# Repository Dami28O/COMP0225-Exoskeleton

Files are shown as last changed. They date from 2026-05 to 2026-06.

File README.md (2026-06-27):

# TSA Wearable Exosuit — Sit-to-Stand Assistance

<p align="center">
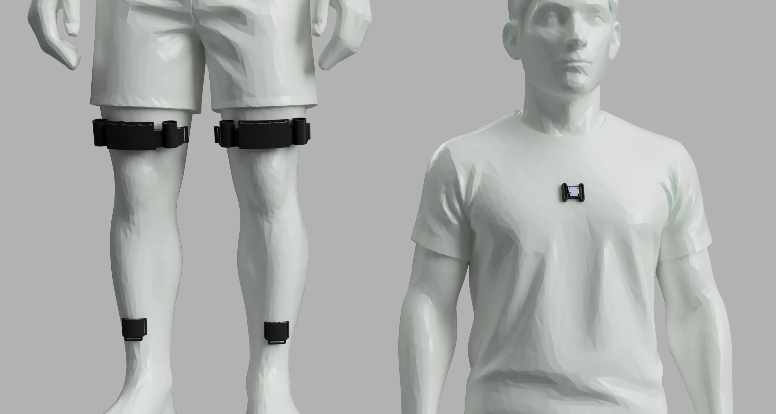
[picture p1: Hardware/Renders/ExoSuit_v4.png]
ExoSuit v4 render
  
</p>

A Twisted String Actuator (TSA) based wearable exosuit designed to assist users through sit-to-stand (STS) motions. Motor performance is optimised using Proximal Policy Optimisation (PPO). An IMU-based intention detection system determines when to trigger the device, and a MuJoCo/MyoSuite musculoskeletal simulation validates the assist strategy before physical deployment.

---

## Results

- **Muscle activation reduction:** 10% reduction in lower-limb muscle activation on a single test subject
- **Intention detection accuracy:** 84.38% overall — limited by false positives from similar forward-lean motions (e.g. bending to tie shoelaces)
- **Control optimisation:** PPO-optimised TSA parameters (string length, staggered motor activation times) minimise quadriceps demand while tracking baseline kinematics

---

## System Overview

```
┌─────────────────────────────────────────────────────┐
│                   Wearable Exosuit                  │
│                                                     │
│  ┌──────────────────┐     ┌──────────────────────┐  │
│  │ Intention        │────▶│ Hardware Control     │  │
│  │ Detection (IMU)  │     │ (TSA Motors + EMG)   │  │
│  └──────────────────┘     └──────────────────────┘  │
│                                    ▲                │
│  ┌──────────────────┐              │                │
│  │ Simulation &     │──── PPO ─────┘                │
│  │ Optimisation     │  optimised params             │
│  └──────────────────┘                               │
└─────────────────────────────────────────────────────┘
```

The three subsystems map directly to the three directories in this repository.

---

## Repository Structure

```
COMP0225-Group3/
│
├── Hardware/
│   ├── MotoronWifiControl.ino   # Arduino firmware — motor control + EMG logging
│   └── Renders/
│       └── ExoSuit_v4.png       # CAD render of the physical device
│
├── IntentionDetection/
│   ├── intent-detect.py         # Finite state machine — real-time STS intent detection
│   ├── complimentary-filter.py  # Complementary filter orientation estimate
│   ├── madgwick-filter.py       # Madgwick filter implementation
│   ├── visualise.py             # Sensor data visualisation
│   ├── read-all.py              # Raw IMU data logger
│   └── icm20948-python-main/    # ICM-20948 IMU driver (third-party)
│
└── Simulation/                  # See Simulation/README.md for full detail
    ├── train_ppo.py             # PPO training — torque-tracking reward
    ├── train_ppo_min_control.py # PPO training — min-control / baseline-tracking
    ├── train_ppo_feedback.py    # PPO training — multi-step feedback controller
    ├── run_optimal.py           # Replay best PPO policy
    ├── ctrl_optim/              # PPO wrappers, STS reflex controller, TSA integration
    ├── tsa_modelling/           # TSA physics (string geometry + motor ODE)
    └── myoassist/               # MyoSuite fork with TorsoLegs environment
```

---

## Hardware

The physical exosuit uses four Motoron motor controllers (I²C addresses 1–4), each driving two motors, giving eight TSA motors in total (four per leg). The microcontroller is an Arduino GIGA R1, which runs the firmware at `Hardware/MotoronWifiControl.ino`.

**Key firmware features:**

- Wi-Fi web interface for manual speed control and braking during development
- Continuous EMG logging via a MyoWare sensor on analogue pin A0 (12-bit, 50 ms interval)
- Acceleration and deceleration limits (400 counts/s²) on all motors to prevent jerk
- Three control modes: `DRIVE`, `BRAKE` (active braking at 800 counts), and `COAST`
- Command timeout (2 s) — motors safe-stop automatically if communication is lost

The TSA motors are twisted-string actuators: a brushed DC motor winds a pair of strings, converting rotation into linear contraction. This contraction applies an extension torque at the knee joint without any rigid linkage on the exosuit frame.

---

## Intention Detection

**Directory:** `IntentionDetection/`

The intention detection system uses an ICM-20948 9-DOF IMU mounted on the torso. Orientation is estimated in real time using a Madgwick filter (quaternion-based, fused accelerometer + gyroscope + magnetometer). The filtered pitch angle and its rate of change feed a finite state machine that fires a motor trigger when a sit-to-stand intent is confirmed.

**Detection rules (all must hold simultaneously):**

| Rule | Condition | Value |
|---|---|---|
| Forward lean | Pitch > threshold | 15° |
| Active lean | Pitch velocity > threshold | 20°/s |
| Positive acceleration | Smoothed pitch accel > 0 | 10-sample window |
| Sustained | Held for duration | 300 ms |
| Cooldown | Minimum gap between triggers | 5 s |

**Performance:** 84.38% overall accuracy. The primary source of false positives is other forward-lean motions — bending over to tie shoelaces, pick something up from the floor, etc. — which produce a similar pitch signature.

Additional scripts:

- `complimentary-filter.py` — earlier complementary filter orientation estimate
- `visualise.py` — real-time and post-hoc sensor data plots
- `read-all.py` — raw IMU data logger for offline analysis

---

## Simulation & Optimisation

**Directory:** `Simulation/` — see [`Simulation/README.md`](Simulation/README.md) for full documentation.

A MuJoCo/MyoSuite simulation drives the optimisation. The musculoskeletal model (`TorsoLegs`) has ~80 Hill-type muscles. A 4-phase reflex-based biological controller executes the STS motion; the TSA exosuit layer injects additional knee-extension torque on top.

**TSA physics** are modelled explicitly:

- String contraction: `X(θ) = L − sqrt(L² − (θ·r)²)`
- Motor dynamics: RK4 ODE integrator, handles stall and wall conditions
- 4-motor-per-leg layout with staggered activation times and symmetric frontal moment cancellation

**Three PPO pipelines** are implemented, all using Stable Baselines 3:

| Pipeline | Optimises | Reward focus |
|---|---|---|
| Torque-tracking | String length + 4 activation times | Minimise torque under-delivery |
| Min-control | String length + 4 activation times | Reduce VAS activation, track baseline kinematics |
| Feedback | Per-step torque commands | Real-time adaptive assist (22-feature observation) |

The min-control pipeline was used to derive the parameters deployed on the physical device.

### Quick Start

```bash
# Activate simulation environment
source Simulation/myoassist/.myo-venv/bin/activate

# Run one STS episode manually
mjpython Simulation/base_code.py

# Train with min-control PPO
mjpython Simulation/train_ppo_min_control.py --timesteps 5000 --out Simulation/logs/test_run

# Evaluate best parameters
mjpython Simulation/ctrl_optim/eval_best_min_control.py --run Simulation/logs/test_run
```

All simulation scripts require `mjpython` (MuJoCo's bundled Python runtime). See `Simulation/README.md` for the full command reference, configuration options, evaluation scripts, and plotting tools.

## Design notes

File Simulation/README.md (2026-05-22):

# TSA Exoskeleton — Sit-to-Stand Simulation

MuJoCo/MyoSuite simulation of a Twisted String Actuator (TSA) knee exoskeleton assisting a musculoskeletal model through sit-to-stand (STS). Includes a reflex-based biological controller, TSA physics, and three PPO training pipelines.

---

## Project Structure

```
TSAExoskeletonSTS/
│
├── base_code.py                    # Run one STS episode manually (useful for debugging)
├── train_ppo.py                    # PPO training — torque-tracking reward
├── train_ppo_min_control.py        # PPO training — min-control / baseline-tracking reward
├── train_ppo_feedback.py           # PPO training — multi-step feedback controller
├── train_ppo_feedback_resume.py    # Resume a feedback PPO run from a checkpoint
├── run_optimal.py                  # Replay best PPO policy deterministically
├── plot_tsa_log.py                 # Plot TSA actuator state logs (CSV → PNG)
├── plot_diag_p4.py                 # Plot Phase 3→4 stability diagnostics
│
├── ctrl_optim/
│   ├── sts_ctrl.py                 # 4-phase STS reflex controller (core sim loop)
│   ├── sts_ctrl_ari.py             # Reference controller variant (read-only)
│   ├── tsa_integration_full.py     # 4-motor-per-leg TSA physics wrapper
│   ├── tsa_integration.py          # Single-motor-per-leg wrapper (earlier version)
│   ├── ppo_wrapper.py              # Gymnasium env — torque-tracking PPO
│   ├── ppo_wrapper_min_control.py  # Gymnasium env — min-control PPO
│   ├── ppo_feedback_wrapper.py     # Gymnasium env — multi-step feedback PPO
│   ├── ppo_config.py               # Shared config dataclass for all PPO runs
│   ├── grid_search.py              # Grid search over TSA params (pre-PPO baseline)
│   ├── eval_best_min_control.py    # Replay best sampled θ from a min-control run
│   ├── extract_muscle_log.py       # Compare baseline vs TSA muscle activation
│   └── ppo_evaluation/
│       ├── compare_baseline_assisted.py  # Side-by-side plots + effort summary
│       ├── plot_ppo_eval.py              # Per-episode reward curve plots
│       └── plot_reward_curve.py          # Reward curve from training CSV
│
├── tsa_modelling/
│   ├── model_v2.py                 # TSASimulator — string geometry + speed-torque curve
│   └── actuator.py                 # TSAActuator — RK4 motor ODE integrator
│
├── myoassist/                      # MyoSuite fork with TorsoLegs environment
├── observations/                   # Notes on observations, stability, TSA signals
├── support_docs/                   # Handoff notes, model notes, design docs
└── logs/                           # Training outputs (git-ignored)
```

---

## Simulation Environment

The model is `TorsoLegs`, registered by MyoSuite. It's a lower-body musculoskeletal model with ~80 Hill-type muscles, driven by activation signals in [0, 1]. The root is defined by three joints: `root_x` (slide), `root_z` (slide), `root_pitch` (hinge) — not a free-joint quaternion.

```bash
from myosuite.utils import gym
env = gym.make("TorsoLegs")
```

All scripts require `mjpython` (MuJoCo's bundled Python runtime) rather than the system Python:

```bash
source myoassist/.myo-venv/bin/activate
which mjpython
```

---

## TSA Physics Model

### String geometry (`tsa_modelling/model_v2.py`)

Contraction as a function of motor angle θ:

```
X(θ) = L − sqrt(L² − (θ·r)²)
```

`L` is the untwisted string length (the key PPO-optimised parameter). `J = dX/dθ` maps motor speed to cable speed.

### Motor ODE (`tsa_modelling/actuator.py`)

`TSAActuator.step()` runs RK4 at each sim timestep. Three branches:

| Branch | Condition | Behaviour |
|---|---|---|
| `at_wall` | X ≥ X_max | String fully wound; motor stalls |
| `load_stalled` | τ_desired > τ_available | Motor stalls against load |
| `advancing` | Otherwise | Full EOM integration: I·θ̈ = τ_cmd − τ_load |

Returns `tension`, `torque`, `X`, `theta`, `theta_dot`, `at_wall`, `load_stalled`.

Key motor parameters (set in `tsa_integration_full.py → _build_tsa_sim`):

| Parameter | Value |
|---|---|
| `radius` | 4 mm |
| `max_motor_torque` | 0.1668 N·m (1.7 kg·cm) |
| `no_load_speed` | 800 RPM |
| `pretension_theta` | 20π rad (10 turns) |
| `max_contraction_ratio` | 0.30 |

---

## TSA Integration (`ctrl_optim/tsa_integration_full.py`)

**4-motor layout per leg.** Two central motors (offset 0°), one at +8°, one at −8°. Sagittal torque per motor: `τ_i = T_i × d × cos(α_i)`. Symmetric ±α pairs cancel frontal moments.

**Staggered activation.** Each motor has an `activation_time` [s]; it's inactive until `t >= activation_time`. PPO optimises these times.

**Cable slack model.** A motor delivers zero torque until its contraction `X` exceeds the geometric slack threshold:
```
X_geom = X₀ + MOMENT_ARM × max(0, knee_initial − knee_current)
```

**Torque injection into MuJoCo:**
```python
sim.data.qfrc_applied[knee_dadr] -= result['torque']
```
Applied directly to `qfrc_applied` at the knee DOF — no muscle signals are modified.

**Control mode:** `full_power` is the default. Each active motor is commanded at `T_des = 1e6 N` (clamped internally to τ_stall at current speed). `demand_share` mode exists for comparison but under-delivers during early wind-up.

`tsa_integration.py` is the single-motor-per-leg predecessor — still used by `ppo_wrapper.py` but superseded by the full 4-motor version.

---

## STS Reflex Controller (`ctrl_optim/sts_ctrl.py`)

Phase-gated reflex controller. Each muscle group gets a stimulation signal proportional to sensory error (joint deviation, pelvis velocity, etc.) gated by the current phase.

| Group | Role |
|---|---|
| `GLU` | Hip extension |
| `VAS` | Knee extension |
| `SOL` | Ankle plantarflexion |
| `TA` | Dorsiflexion |
| `HFL` | Hip flexion |
| `HAM` | Hamstrings |
| `TORSO_EXT / FLEX` | Spinal stabilisation |

### Phases

| Phase | Description | Key entry condition |
|---|---|---|
| 1 | Lean forward | Start; root and feet held |
| 2 | Seat-off | `trunk_lean_rel ≤ p1_lean_target` |
| 3 | Extension/rise | Pelvis rising, lean safe, torso not collapsing |
| 4 | Stabilisation | Pelvis height, contacts, lean all within tolerance |

All phase timings and thresholds live in `STSReflexParams`. `leg_scale` can be passed to `apply_leg_control_reduction()` to simulate reduced lower-limb control capacity.

---

## PPO Optimisation

Three separate pipelines, all using SB3 PPO. They share `ppo_config.py` for hyperparameters.

### 1. Torque-tracking (`train_ppo.py` + `ppo_wrapper.py`)

**What's being optimised:** θ = [L, t0, t1, t2, t3] — string length and 4 staggered motor activation times. Symmetric across legs (5-D action). `t0 ≤ t1 ≤ t2 ≤ t3` enforced by sorting.

**Reward:**
```
R = w_torque · R_torque + w_muscle · R_muscle + w_time · R_time
```
`R_torque` is a one-sided integral: only penalises under-delivery (delivered torque < α × knee demand). This prevents reward-hacking by late/no activation.

**Architecture:** One PPO timestep = one full STS rollout. `terminated=True` always so SB3 immediately starts a new episode.

```bash
mjpython train_ppo.py
mjpython train_ppo.py --timesteps 2000 --out logs/ppo_quick
mjpython train_ppo.py --config path/to/config.json
```

---

### 2. Min-control / baseline-tracking (`train_ppo_min_control.py` + `ppo_wrapper_min_control.py`)

Same one-step structure (θ = [L, t0..t3]), different reward. A reference trajectory is generated once from the working baseline controller (no TSA). Each rollout is rewarded for:

- Staying close to the baseline kinematics (position + velocity tracking)
- Reducing VAS (quadriceps) activation
- Not using excessive TSA torque
- Completing the STS and matching baseline duration

**Reward:**
```
R = w_success · R_success
  + w_track_pos · R_track_pos
  + w_track_vel · R_track_vel
  + w_muscle · R_muscle
  + w_tsa · R_tsa
  + w_stability · R_stability
  + w_time · R_time
```

Default weights are set inline in `_run_episode` — adjust there first. They can be moved to `ppo_config.py` once stable.

```bash
mjpython train_ppo_min_control.py
mjpython train_ppo_min_control.py --timesteps 5000 --out logs/ppo_min_control_run1
```

---

### 3. Multi-step feedback PPO (`train_ppo_feedback.py` + `ppo_feedback_wrapper.py`)

Different architecture from 1 and 2. PPO is a real timestep-level feedback controller:

- **Observation:** normalised skeleton state (22 features — phase, heights, velocities, joint angles, contacts)
- **Action:** `[assist_r, assist_l]` ∈ [0, 1] — idealised knee-extension torque commands at each step
- **Reward:** per-step composite (progress, posture, velocity, muscle, assist effort, contact, symmetry)

The biological STS controller is still running; PPO adds torque on top. Leg control can be scaled down (`--leg-scale`) to simulate impaired users.

```bash
mjpython train_ppo_feedback.py --timesteps 100000 --out logs/ppo_feedback_100k
mjpython train_ppo_feedback.py --timesteps 20000 --tau-max 40 --leg-scale 0.7
mjpython train_ppo_feedback_resume.py --run logs/ppo_feedback_100k --timesteps 50000
```

---

## Configuration (`ctrl_optim/ppo_config.py`)

`TSAOptimConfig` is a nested dataclass used by all three pipelines. Pass as JSON:

```json
{
  "total_timesteps": 10000,
  "env_params": { "L_min": 0.30, "L_max": 0.60, "t_max": 0.55 },
  "reward_params": { "w_muscle": 2.0, "support_fraction": 0.2 },
  "ppo_params": { "learning_rate": 1e-4, "n_steps": 128 }
}
```

Key tuning knobs:

| Parameter | Default | Effect |
|---|---|---|
| `w_torque` | 0.0 | Torque-tracking weight |
| `w_muscle` | 1.0 | Quadriceps relief weight |
| `support_fraction` | 0.1 | Target exo share of knee demand (α) |
| `t_max` | 0.65 s | Cap on motor activation times — above ~0.6 s motors can miss the STS window |
| `L_min / L_max` | 0.25–0.65 m | String length search bounds |

---

## Training Outputs

Each run creates a directory under `logs/`:

```
logs/ppo_min_control_<timestamp>/
├── config.json                  # Exact config used
├── min_control_components.csv   # Per-episode: reward, R_* components, L, t0..t3
├── best_sampled_theta.json      # Best θ seen during training
├── tensorboard/                 # TensorBoard event files
└── checkpoints/                 # Model checkpoints every 200 episodes
```

---

## Evaluation

### Replay best sampled θ

```bash
mjpython ctrl_optim/eval_best_min_control.py --run logs/ppo_min_control_<timestamp>
```

Loads `best_sampled_theta.json`, runs one rollout with `debug=True` and `log_to_csv=True`, prints reward components and final state.

### Baseline vs assisted comparison

Run two rollouts (one without TSA, one with the optimised θ) and save CSVs with `log_to_csv=True, log_tag="..."` in `base_code.py`. Then:

```bash
python ctrl_optim/ppo_evaluation/compare_baseline_assisted.py \
    --baseline logs/baseline_diag.csv \
    --assisted logs/ppo_best_eval_diag.csv \
    --tsa      logs/ppo_best_eval_tsa.csv \
    --out      logs/comparison_plots/
```

Outputs 5 comparison plots (height, joints, posture, leg stimulation, torso stimulation) and a `muscle_effort_summary.csv` with per-muscle AUC reduction percentages.

### Muscle signal extraction

```bash
mjpython ctrl_optim/extract_muscle_log.py
```

Runs baseline and TSA-enabled rollouts back-to-back, logs VAS/knee demand/delivered torque per step, and prints a per-phase summary table.

### Reward curves

```bash
python ctrl_optim/ppo_evaluation/plot_reward_curve.py --csv logs/ppo_min_control_<timestamp>/min_control_components.csv
python ctrl_optim/ppo_evaluation/plot_ppo_eval.py --csv logs/ppo_min_control_<timestamp>/min_control_components.csv
```

---

## Plotting

### TSA actuator state (`plot_tsa_log.py`)

```bash
mjpython plot_tsa_log.py                       # reads logs/tsa_log.csv
mjpython plot_tsa_log.py path/to/tsa_log.csv
```

Plots knee angle, torque demand vs delivered, number of active motors, per-motor contraction (with X_geom slack threshold), tension, and joint resistance. Phase boundaries are marked.

### Phase 3→4 diagnostics (`plot_diag_p4.py`)

```bash
mjpython plot_diag_p4.py
```

Reads `logs/diag_p4.csv` (written when `debug=True`). Shows pelvis height, root pitch, lean, knee/hip/ankle angles, muscle activations, and pitch velocity. Use this to diagnose why Phase 4 was never reached.

---

## Quick Start

```bash
# 1. Activate environment
source myoassist/.myo-venv/bin/activate

# 2. Test one episode manually
mjpython base_code.py

# 3. Run min-control PPO training
mjpython train_ppo_min_control.py --timesteps 5000 --out logs/test_run

# 4. Evaluate the best parameters found
mjpython ctrl_optim/eval_best_min_control.py --run logs/test_run
```

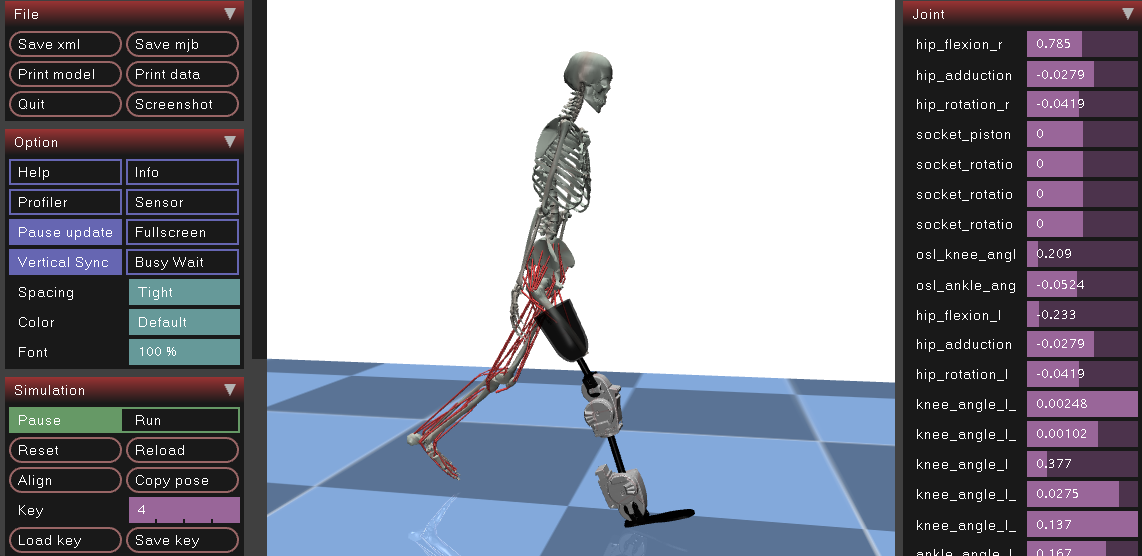
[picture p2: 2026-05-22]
Simulation/myoassist/docs/assets/modeling.png

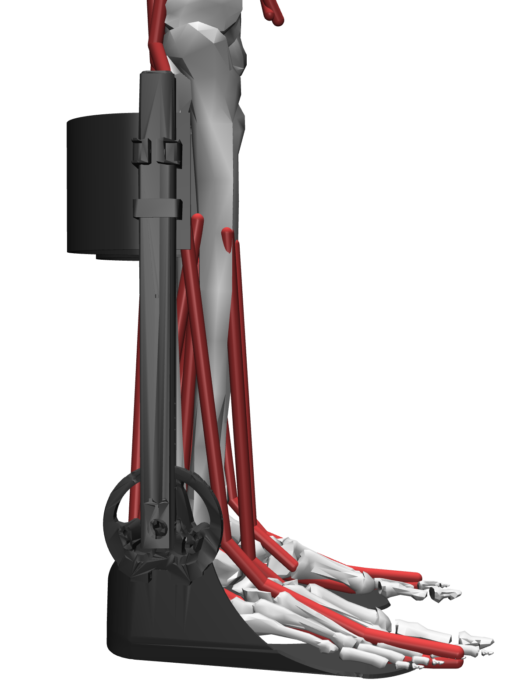
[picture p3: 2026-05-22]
Simulation/myoassist/docs/assets/openexo_detail.png

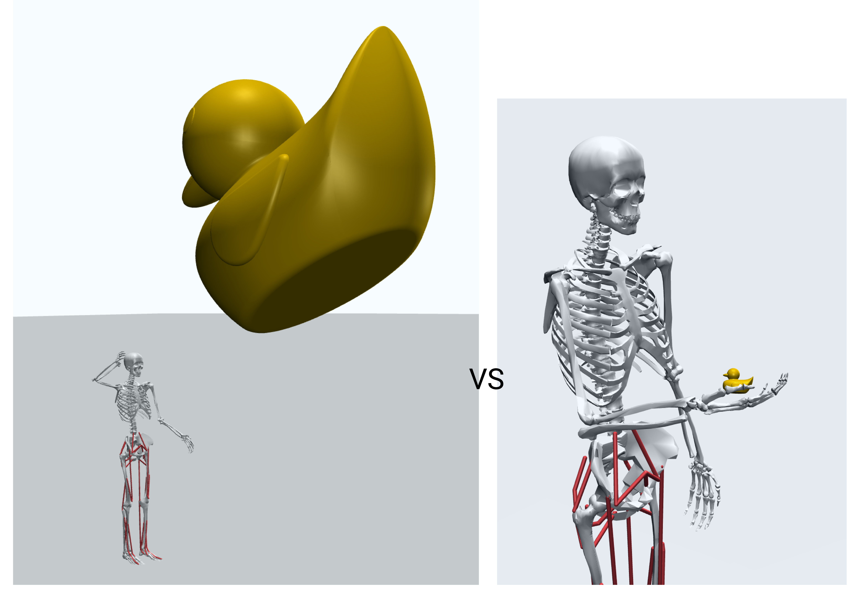
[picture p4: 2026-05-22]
Simulation/myoassist/docs/assets/ducks.png

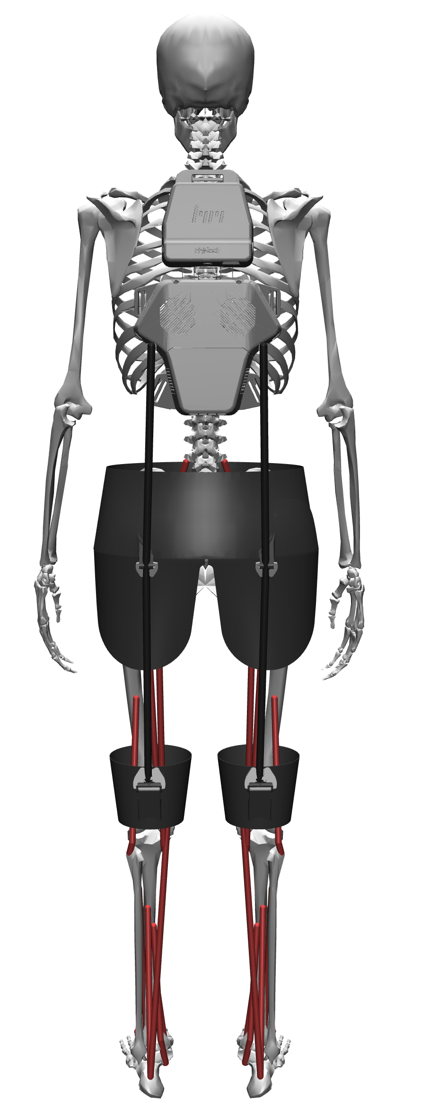
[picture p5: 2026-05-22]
Simulation/myoassist/docs/assets/hmedi.png

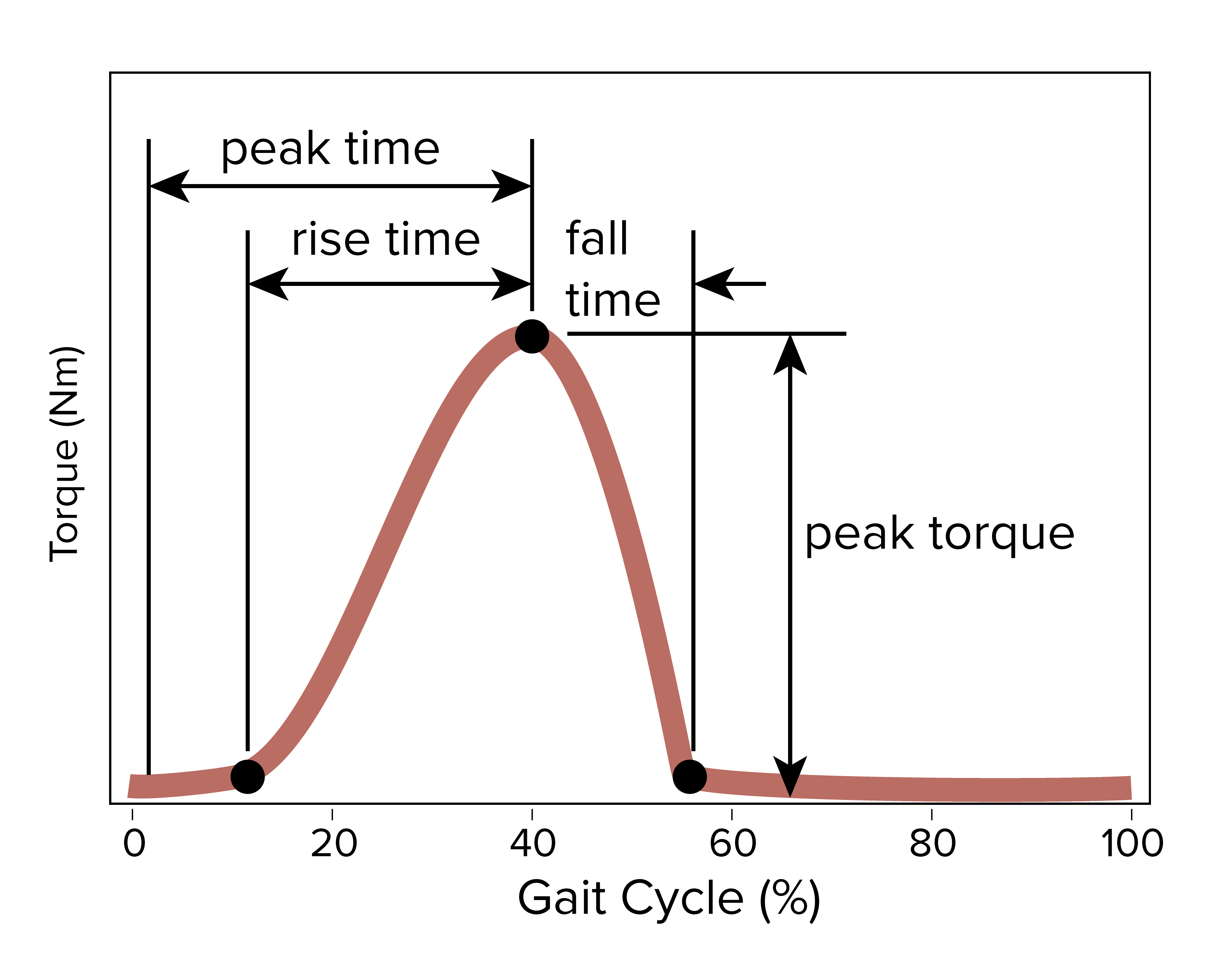
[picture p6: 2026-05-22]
Simulation/myoassist/docs/assets/4param.png

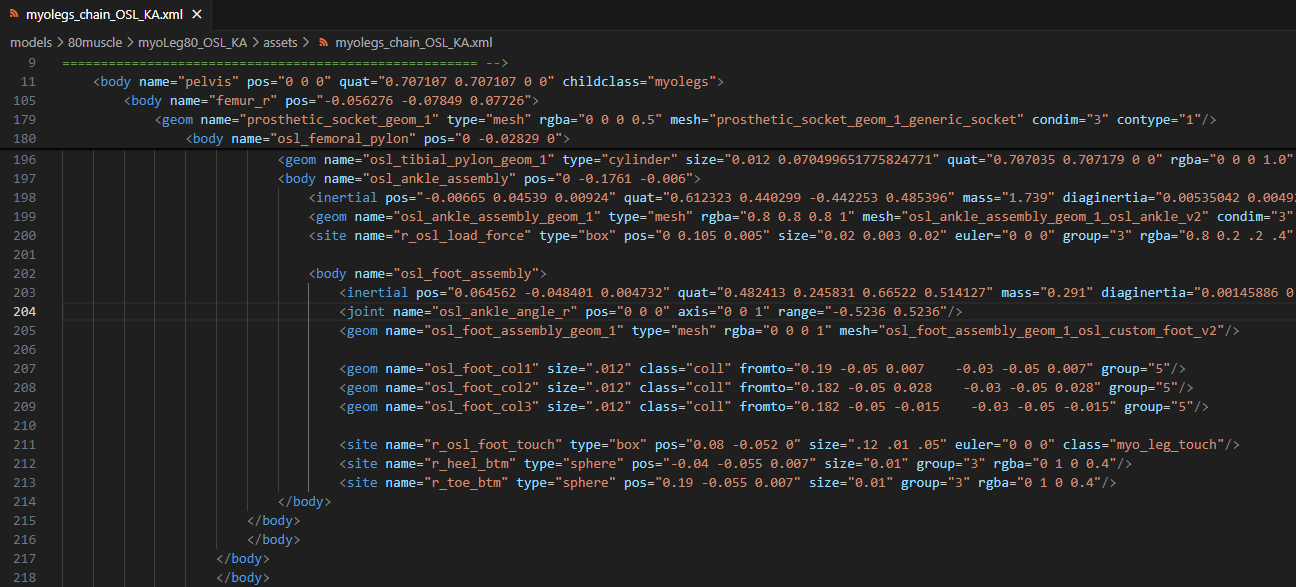
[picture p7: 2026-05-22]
Simulation/myoassist/docs/assets/modeling_xml.png

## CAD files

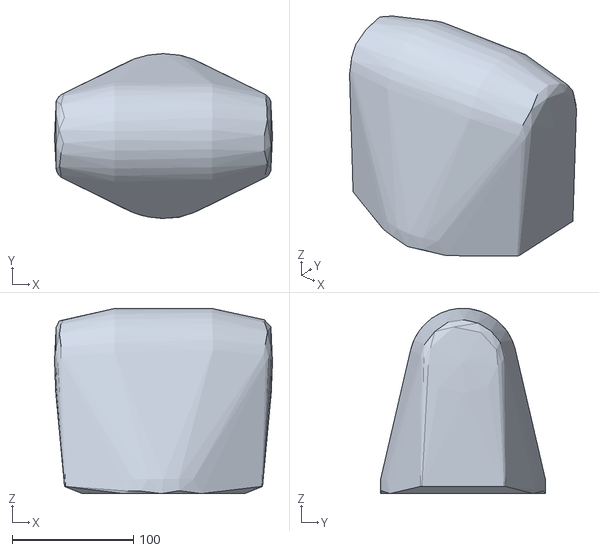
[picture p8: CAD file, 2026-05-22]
Simulation/myoassist/myosuite/simhive/MPL_sim/meshes/hdm/torso_yaw_axis_assembly_top-2_cvx.stl
180.0 x 136.0 x 152.9

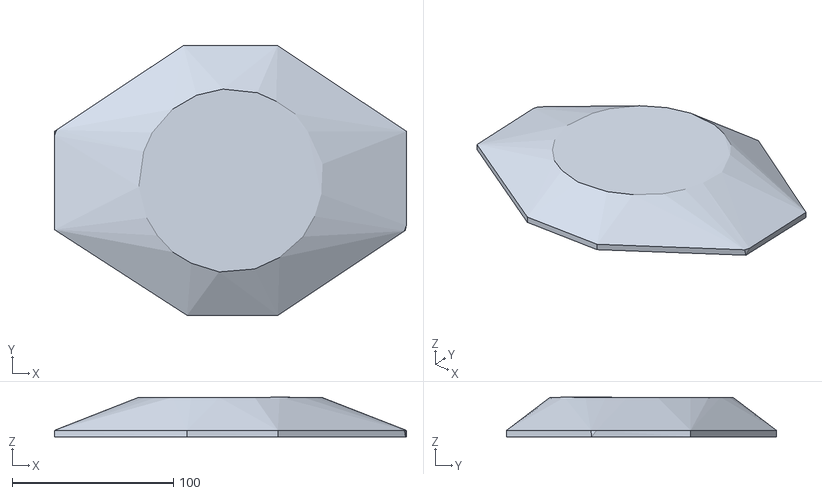
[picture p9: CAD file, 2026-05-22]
Simulation/myoassist/myosuite/simhive/MPL_sim/meshes/hdm/torso_yaw_axis_assembly_bottom-1_cvx.stl
218.4 x 167.4 x 24.5

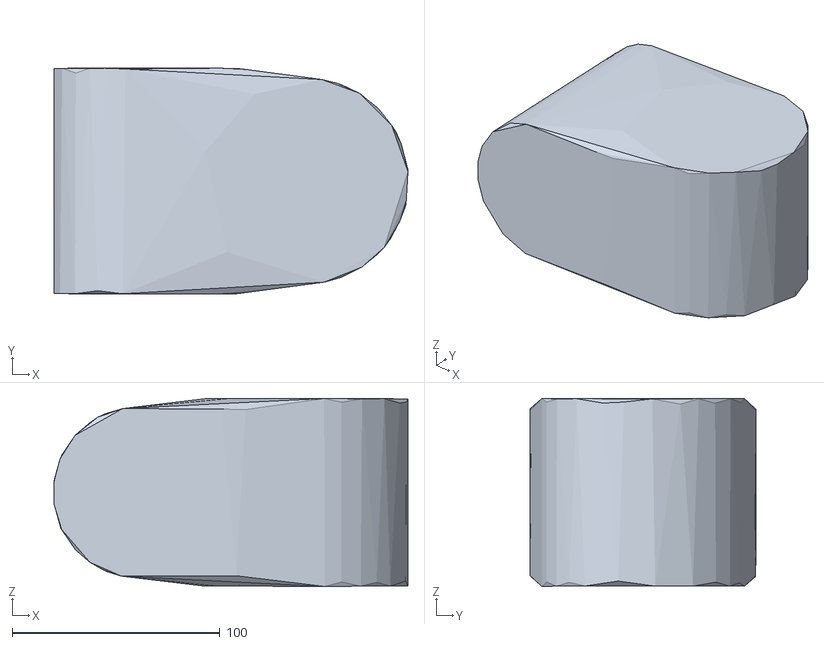
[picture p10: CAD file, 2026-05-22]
Simulation/myoassist/myosuite/simhive/MPL_sim/meshes/hdm/roll_slip_yoke_assembly-3_cvx.stl
170.3 x 108.6 x 90.5

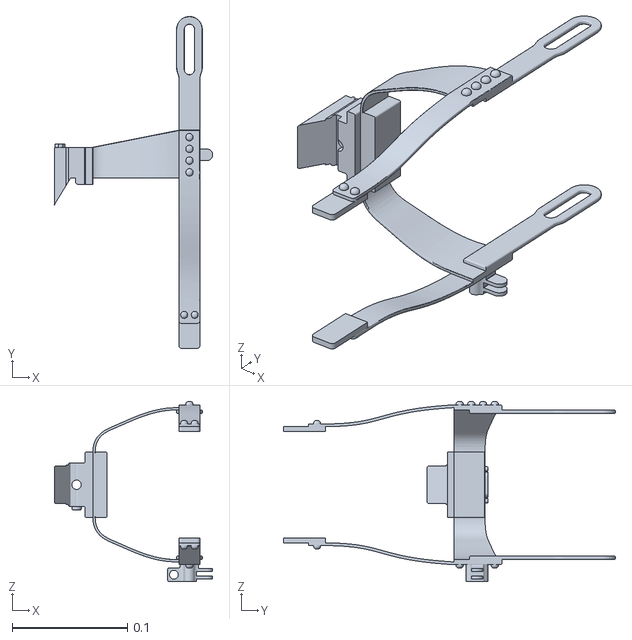
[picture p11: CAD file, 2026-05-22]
Simulation/myoassist/models/mesh/Humotech/Shin Main L.stl
0.137 x 0.288 x 0.156

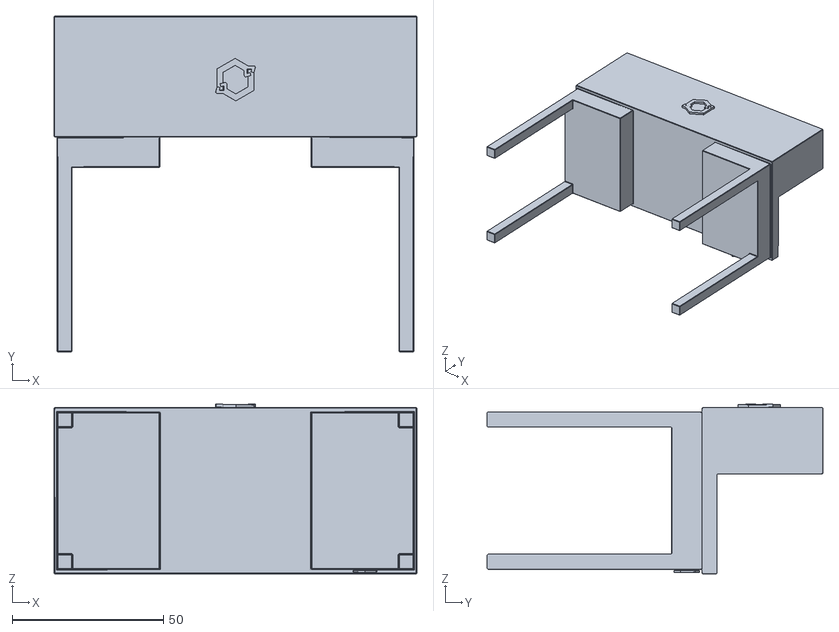
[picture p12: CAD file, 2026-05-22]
Simulation/myoassist/myosuite/simhive/furniture_sim/studyTable/meshes/studyTable_Main.stl
120.0 x 111.0 x 56.1

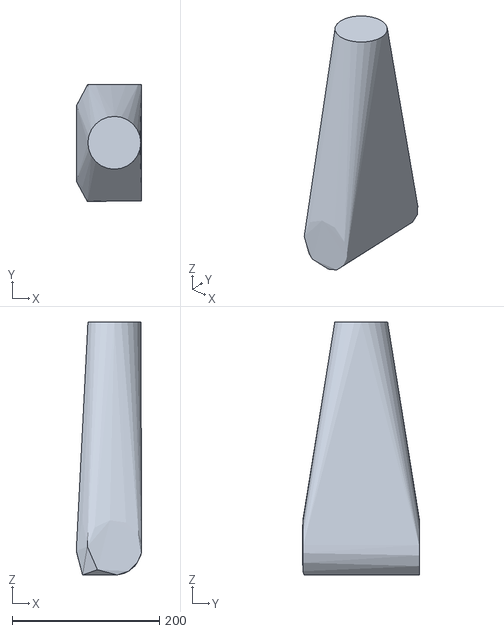
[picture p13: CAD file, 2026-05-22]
Simulation/myoassist/myosuite/simhive/MPL_sim/meshes/hdm/upper_torso_assembly-5_cvx.stl
88.8 x 159.2 x 343.1

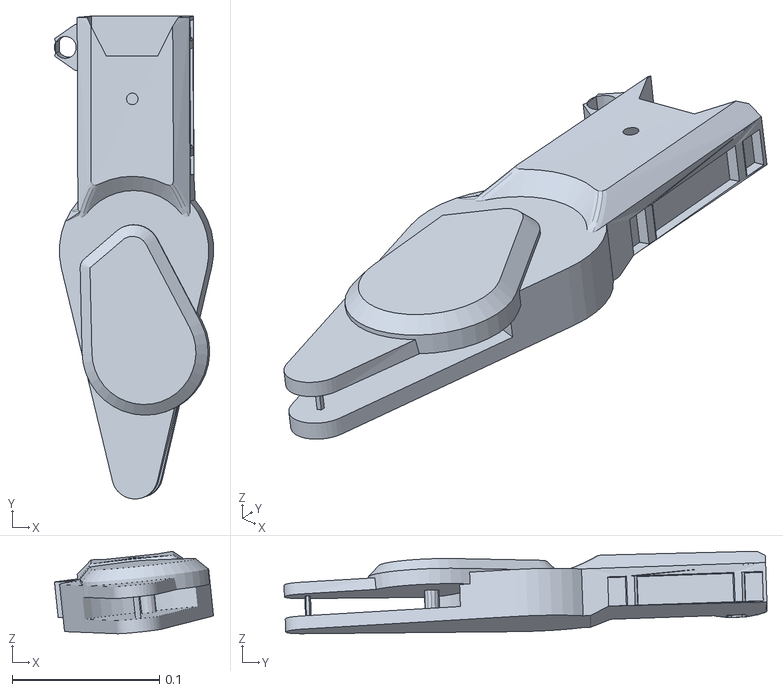
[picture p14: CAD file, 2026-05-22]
Simulation/myoassist/models/mesh/Dephy/exo_main_r.stl
0.108 x 0.328 x 0.056

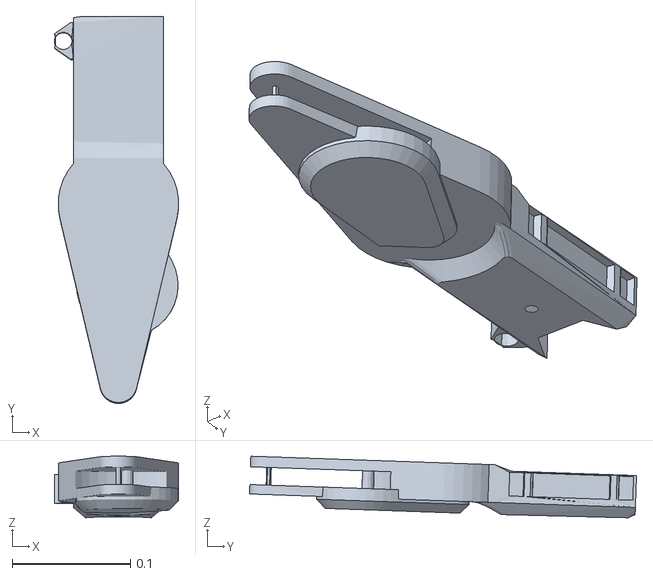
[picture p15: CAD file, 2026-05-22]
Simulation/myoassist/models/mesh/Dephy/exo_main_l.stl
0.105 x 0.328 x 0.0522

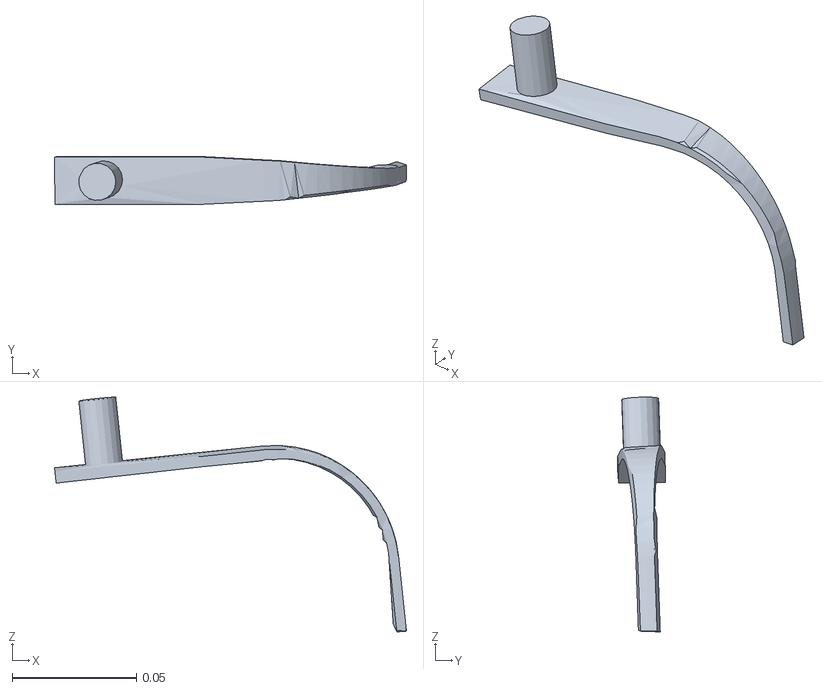
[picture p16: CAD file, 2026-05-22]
Simulation/myoassist/models/mesh/Dephy/exo_clink_r.stl
0.142 x 0.0192 x 0.0945

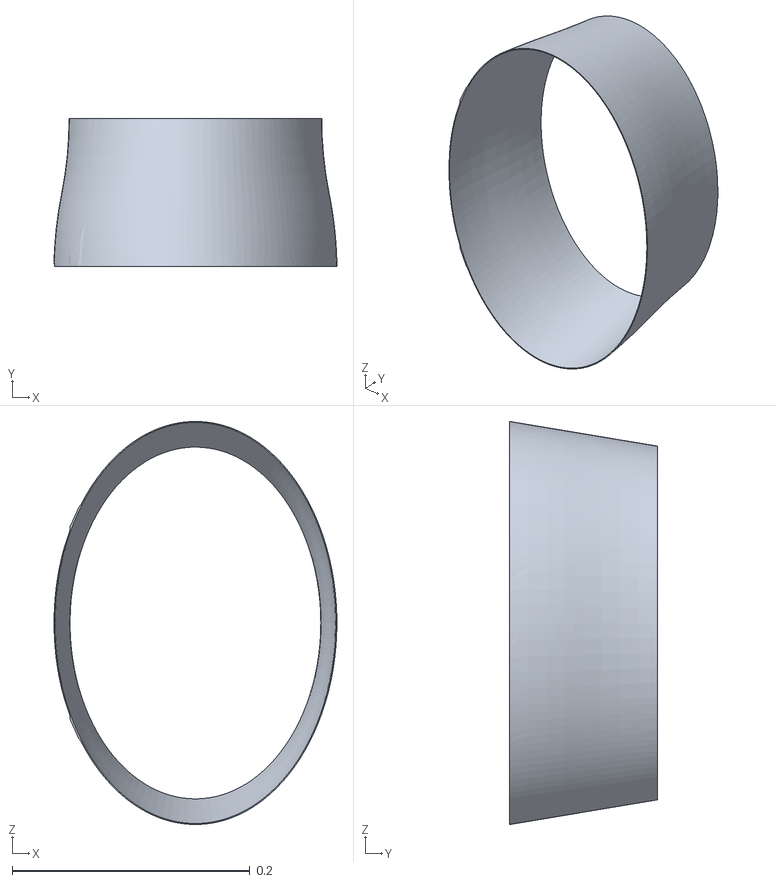
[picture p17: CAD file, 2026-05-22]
Simulation/myoassist/models/mesh/HMEDI/ASSEM_MEDI WaistBand.stl
0.238 x 0.124 x 0.339

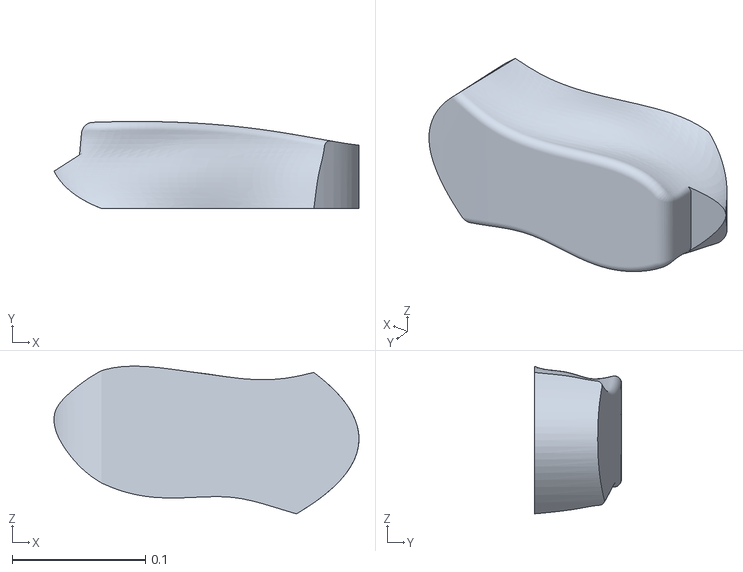
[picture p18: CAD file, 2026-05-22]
Simulation/myoassist/models/mesh/Humotech/Aft Sole L.stl
0.229 x 0.0654 x 0.111

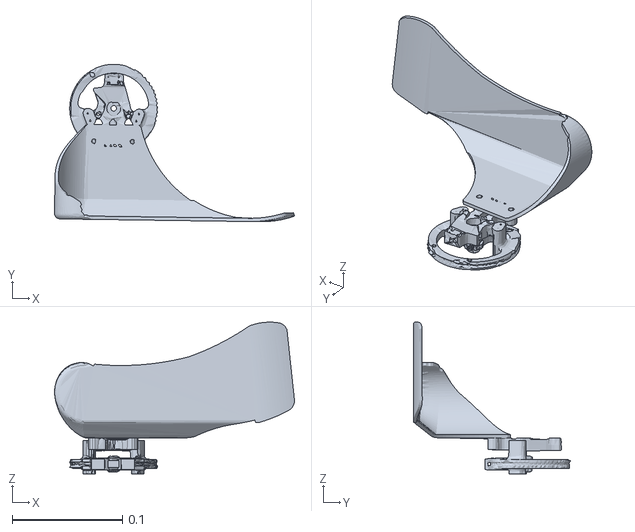
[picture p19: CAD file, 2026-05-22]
Simulation/myoassist/models/mesh/OpenExo/blade_l.stl
0.218 x 0.143 x 0.138

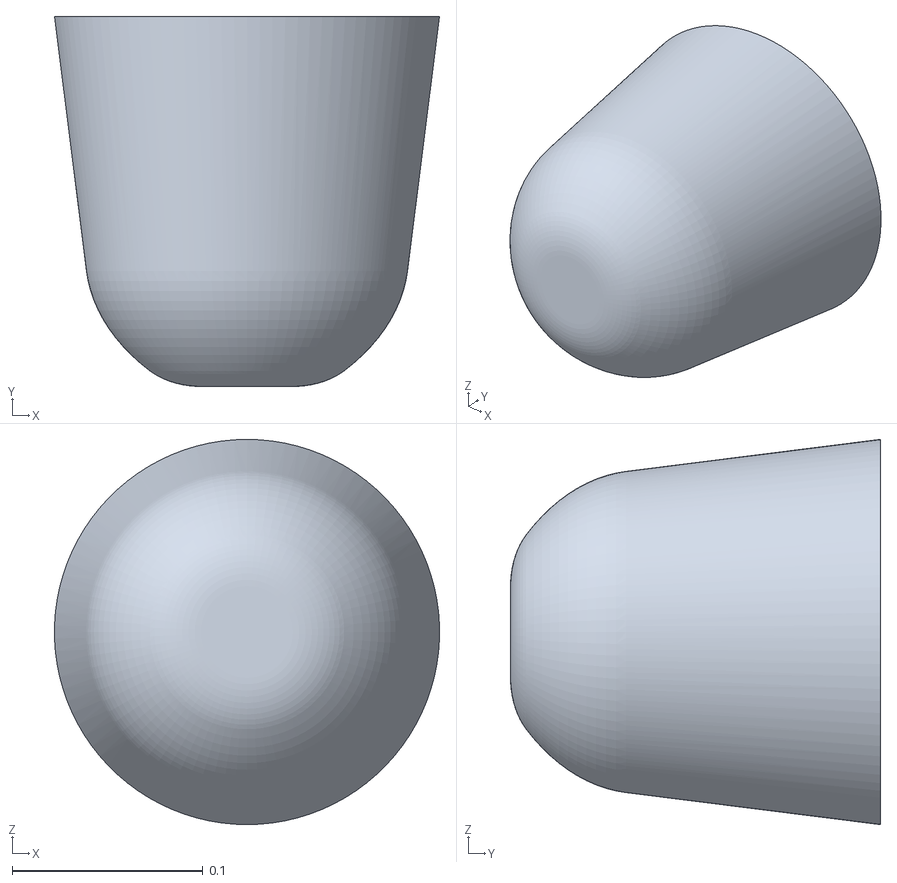
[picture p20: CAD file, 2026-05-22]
Simulation/myoassist/models/mesh/OSL/osl_generic_socket_enlarged.stl
0.202 x 0.194 x 0.202

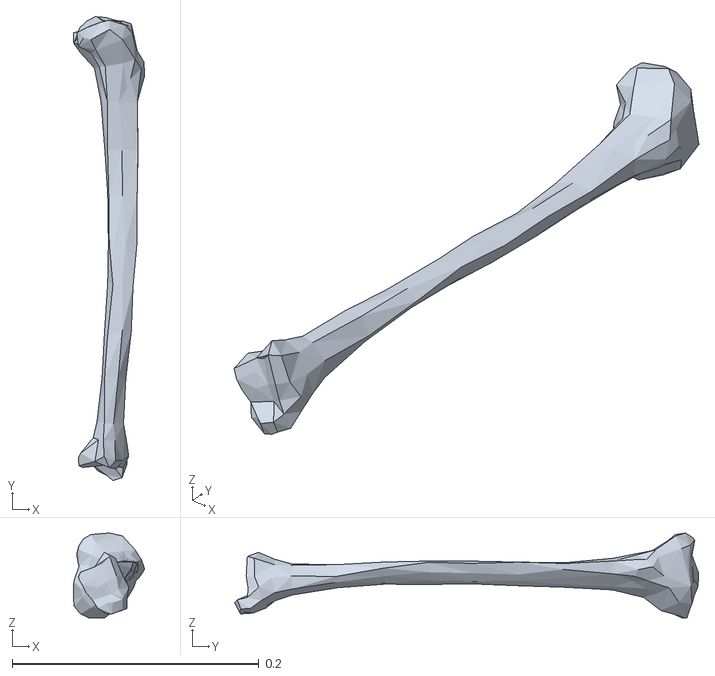
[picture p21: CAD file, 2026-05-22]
Simulation/myoassist/models/mesh/r_tibia.stl
0.0575 x 0.376 x 0.0689

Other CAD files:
Simulation/myoassist/myosuite/simhive/MPL_sim/meshes/hdm/roll_slip_yoke_assembly_top-4_cvx.stl
Simulation/myoassist/models/mesh/Humotech/Shin Main R.stl
Simulation/myoassist/models/mesh/TSAmodel/models/TSAmesh/leg_R.stl
Simulation/myoassist/models/mesh/Tutorial/foot_attachment_r.stl
Simulation/myoassist/models/mesh/Dephy/Battery.stl
Simulation/myoassist/models/mesh/Dephy/Fanny pack.stl
Simulation/myoassist/models/mesh/Dephy/Raspberry Pi 5.stl
Simulation/myoassist/models/mesh/Dephy/exo_blink_l.stl
Simulation/myoassist/models/mesh/Dephy/exo_blink_r.stl
Simulation/myoassist/models/mesh/Dephy/exo_clink_l.stl
Simulation/myoassist/models/mesh/Dephy/exo_ilink_l.stl
Simulation/myoassist/models/mesh/Dephy/exo_ilink_r.stl
Simulation/myoassist/models/mesh/Dephy/exo_spad_l.stl
Simulation/myoassist/models/mesh/Dephy/exo_spad_r.stl
Simulation/myoassist/models/mesh/Dephy/tacboot_mid_l.stl
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

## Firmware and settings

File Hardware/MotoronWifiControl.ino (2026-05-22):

#include <WiFi.h>
#include <Motoron.h>
#include "secrets.h"

char ssid[] = SECRET_SSID;
char pass[] = SECRET_PASS;

int status = WL_IDLE_STATUS;

WiFiServer server(80);

#define EMG_PIN A0
int emgValue = 0;

unsigned long lastEmgRead = 0;
const unsigned long EMG_READ_INTERVAL_MS = 50;

MotoronI2C mc1(1);
MotoronI2C mc2(2);
MotoronI2C mc3(3);
MotoronI2C mc4(4);

int16_t motorSpeed = 0;
const int16_t SPEED_STEP = 100;
const int16_t MAX_SPEED = 800;
const int16_t MIN_SPEED = -800;

unsigned long lastMotorRefresh = 0;
const unsigned long MOTOR_REFRESH_INTERVAL_MS = 200;

enum MotorMode
{
  MODE_DRIVE,
  MODE_BRAKE,
  MODE_COAST
};

MotorMode currentMode = MODE_COAST;

void setupMotoron(MotoronI2C &mc)
{
  mc.reinitialize();
  mc.disableCrc();
  mc.clearResetFlag();
  mc.setCommandTimeoutMilliseconds(2000);
}

int16_t clampSpeed(int value)
{
  if (value > MAX_SPEED) return MAX_SPEED;
  if (value < MIN_SPEED) return MIN_SPEED;
  return value;
}

void applySpeed()
{
  currentMode = MODE_DRIVE;

  mc1.setSpeed(1, motorSpeed);
  mc1.setSpeed(2, motorSpeed);

  mc2.setSpeed(1, motorSpeed);
  mc2.setSpeed(2, motorSpeed);

  mc3.setSpeed(1, motorSpeed);
  mc3.setSpeed(2, motorSpeed);

  mc4.setSpeed(1, motorSpeed);
  mc4.setSpeed(2, motorSpeed);
}

void stopMotors()
{
  motorSpeed = 0;
  currentMode = MODE_BRAKE;

  mc1.setBrakingNow(1, 800);
  mc1.setBrakingNow(2, 800);

  mc2.setBrakingNow(1, 800);
  mc2.setBrakingNow(2, 800);

  mc3.setBrakingNow(1, 800);
  mc3.setBrakingNow(2, 800);

  mc4.setBrakingNow(1, 800);
  mc4.setBrakingNow(2, 800);
}

void coastMotors()
{
  motorSpeed = 0;
  currentMode = MODE_COAST;

  mc1.setSpeed(1, 0);
  mc1.setSpeed(2, 0);

  mc2.setSpeed(1, 0);
  mc2.setSpeed(2, 0);

  mc3.setSpeed(1, 0);
  mc3.setSpeed(2, 0);

  mc4.setSpeed(1, 0);
  mc4.setSpeed(2, 0);

  
}

void sendWebPage(WiFiClient &client)
{
  client.println("HTTP/1.1 200 OK");
  client.println("Content-Type: text/html");
  client.println("Connection: close");
  client.println();

  client.println("<!DOCTYPE html>");
  client.println("<html>");
  client.println("<head>");
  client.println("<meta name='viewport' content='width=device-width, initial-scale=1'>");
  client.println("<style>");
  client.println("body{font-family:Arial;text-align:center;margin-top:40px;}");
  client.println("button{font-size:24px;padding:15px 30px;margin:10px;}");
  client.println("input{font-size:24px;width:120px;text-align:center;}");
  client.println("</style>");
  client.println("</head>");

  client.println("<body>");
  client.println("<h1>GIGA Motor Control</h1>");

  client.print("<h2>Current Speed: ");
  client.print(motorSpeed);
  client.println("</h2>");

  client.println("<form action='/set'>");
  client.println("<input type='number' name='speed' min='-800' max='800' value='0'>");
  client.println("<button type='submit'>Set Speed</button>");
  client.println("</form>");

  client.println("<br>");
  client.println("<a href='/inc'><button>Increase</button></a>");
  client.println("<a href='/dec'><button>Decrease</button></a>");
  client.println("<a href='/stop'><button style='background:red;color:white;'>BRAKE STOP</button></a>");
  client.println("<a href='/coast'><button style='background:orange;color:white;'>COAST STOP</button></a>");

  client.println("</body>");
  client.println("</html>");
}

void handleRequest(String request)
{
  if (request.indexOf("GET /inc") >= 0)
  {
    motorSpeed = clampSpeed(motorSpeed + SPEED_STEP);
    applySpeed();
  }
  else if (request.indexOf("GET /dec") >= 0)
  {
    motorSpeed = clampSpeed(motorSpeed - SPEED_STEP);
    applySpeed();
  }
  else if (request.indexOf("GET /stop") >= 0)
  {
    stopMotors();
  }
  else if (request.indexOf("GET /coast") >= 0)
  {
    coastMotors();
  }
  else if (request.indexOf("GET /set?speed=") >= 0)
  {
    int start = request.indexOf("speed=") + 6;
    int end = start;

    while (end < (int)request.length())
    {
      char c = request[end];
      if (c == ' ' || c == '&' || c == '\r' || c == '\n') break;
      end++;
    }

    String speedString = request.substring(start, end);
    int requestedSpeed = speedString.toInt();

    motorSpeed = clampSpeed(requestedSpeed);
    applySpeed();
  }
}

void readEmgIfDue()
{
  if (millis() - lastEmgRead >= EMG_READ_INTERVAL_MS)
  {
    emgValue = analogRead(EMG_PIN);

    Serial.println(emgValue);

    lastEmgRead = millis();
  }
}

void setup()
{
  Serial.begin(115200);
  while (!Serial) {}

  Wire1.begin();

  mc1.setBus(&Wire1);
  mc2.setBus(&Wire1);
  mc3.setBus(&Wire1);
  mc4.setBus(&Wire1);

  setupMotoron(mc1);
  setupMotoron(mc2);
  setupMotoron(mc3);
  setupMotoron(mc4);

  mc1.setMaxAcceleration(1, 400);
  mc1.setMaxDeceleration(1, 400);
  mc1.setMaxAcceleration(2, 400);
  mc1.setMaxDeceleration(2, 400);

  mc2.setMaxAcceleration(1, 400);
  mc2.setMaxDeceleration(1, 400);
  mc2.setMaxAcceleration(2, 400);
  mc2.setMaxDeceleration(2, 400);

  mc3.setMaxAcceleration(1, 400);
  mc3.setMaxDeceleration(1, 400);
  mc3.setMaxAcceleration(2, 400);
  mc3.setMaxDeceleration(2, 400);

  mc4.setMaxAcceleration(1, 400);
  mc4.setMaxDeceleration(1, 400);
  mc4.setMaxAcceleration(2, 400);
  mc4.setMaxDeceleration(2, 400);

  stopMotors();

  pinMode(EMG_PIN, INPUT);
  analogReadResolution(12);
  Serial.println("MyoWare EMG analog read enabled on A0 (12-bit)");

  Serial.print("Connecting to WiFi: ");
  Serial.println(ssid);

  // check for the WiFi module:
  if (WiFi.status() == WL_NO_MODULE) {
    Serial.println("Communication with WiFi module failed.");
    while (true);
  }

  const int MAX_WIFI_ATTEMPTS = 5;
  int wifiAttempts = 0;

  
  while (status != WL_CONNECTED && wifiAttempts < MAX_WIFI_ATTEMPTS) {
    Serial.print("Attempting to connect to SSID: ");
    Serial.print(ssid);
    Serial.print(" (attempt ");
    Serial.print(wifiAttempts + 1);
    Serial.print("/");
    Serial.print(MAX_WIFI_ATTEMPTS);
    Serial.println(")");

    status = WiFi.begin(ssid, pass);
    delay(3000);
    wifiAttempts++;
  }
  
  if (status == WL_CONNECTED) {
    printWifiStatus();
    server.begin();
  } else {
    Serial.println("WiFi connection failed — continuing without web control.");
    Serial.println("EMG serial logging and motor control over reset are still active.");
  }
}

void loop()
{
  readEmgIfDue();
  
  if (millis() - lastMotorRefresh >= MOTOR_REFRESH_INTERVAL_MS)
  {
    if (currentMode == MODE_DRIVE)
    {
      applySpeed();
    }
    else if (currentMode == MODE_BRAKE)
    {
      stopMotors();
    }

    lastMotorRefresh = millis();
  }

  if (WiFi.status() == WL_CONNECTED)
  {
    WiFiClient client = server.available();

    if (client)
    {
      String request = "";
      String currentLine = "";
      unsigned long clientTimeout = millis() + 1000;

      while (client.connected() && millis() < clientTimeout)
      {
        if (client.available())
        {
          char c = client.read();

          if (request.length() == 0 && c != '\n' && c != '\r')
          {
          }

          if (c == '\n')
          {
            if (currentLine.length() == 0)
            {
              break;
            }
            if (request.length() == 0)
            {
              request = currentLine;
            }
            currentLine = "";
          }
          else if (c != '\r')
          {
            currentLine += c;
          }
        }
      }

      Serial.println(request);

      handleRequest(request);

      readEmgIfDue();

      sendWebPage(client);

      delay(1);
      client.stop();
    }
  }
}  
/* -------------------------------------------------------------------------- */
void printWifiStatus() {
/* -------------------------------------------------------------------------- */
  // print the SSID of the network you're attached to:
  Serial.print("SSID: ");
  Serial.println(WiFi.SSID());

  // print your board's IP address:
  IPAddress ip = WiFi.localIP();
  Serial.print("IP Address: ");
  Serial.println(ip);

  // print the received signal strength:
  long rssi = WiFi.RSSI();
  Serial.print("signal strength (RSSI):");
  Serial.print(rssi);
  Serial.println(" dBm");
}

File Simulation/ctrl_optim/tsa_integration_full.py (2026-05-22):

"""
TSA Integration — 4-motor-per-leg configuration.

Extends tsa_integration.py to four independent TSAActuators per leg.
Each motor has a frontal-plane offset α; sagittal torque contribution is
T_i × d × cos(α_i). Symmetric ±α pairs cancel frontal-plane moments.

Control modes: 'full_power' (each active motor runs at τ_stall, recommended)
or 'demand_share' (distributes demanded torque equally; under-delivers early).
Drop-in replacement for TSAIntegration — same step()/reset() signature.
"""

from __future__ import annotations

import sys
from dataclasses import dataclass
from pathlib import Path
from typing import Dict, List, Optional

import numpy as np

_TSA_DIR = Path(__file__).resolve().parent.parent / "tsa_modelling"
if str(_TSA_DIR) not in sys.path:
    sys.path.insert(0, str(_TSA_DIR))

from actuator import TSAActuator
from model_v2 import TSASimulator

# ---------------------------------------------------------------------------
# Physical constants (identical to tsa_integration.py — do not diverge)
# ---------------------------------------------------------------------------

MOMENT_ARM: float = 0.045
"""Perp. distance from knee joint axis to cable line of action [m] — confirmed 4.5 cm."""

CABLE_PATH_ARM: float = 0.025
"""Effective cable path radius at the knee for the geometric slack model [m].
Smaller than MOMENT_ARM because the shin attachment is proximal to the
torque application point, reducing path length change per unit knee rotation.
Used only in X_geom = X0 + CABLE_PATH_ARM * Δangle; MOMENT_ARM is still
used for torque calculation."""

RESISTANCE_SCALE: float = 0.002
"""Fraction of raw joint torque the TSA must resist (muscles bear the rest).
Keep in sync with tsa_integration.py.  See F_resist Design Summary in
HANDOFF_v3.md before changing."""

_PAYLOAD_MASS_INIT: float = 10.0
"""Initial payload_mass for TSASimulator at construction time.
Overwritten per-step by _SHIN_CABLE_MASS — this value is only used
during construction."""

_SHIN_CABLE_MASS: float = 10.0
"""Cable-side equivalent mass [kg] used in the motor EOM each step.
Physical basis: I_shin_about_knee / d²
  Typical human shin+foot: I ≈ 0.10 kg·m², d = 0.045 m → m ≈ 49 kg
Using M_kk/d² (full-body generalised inertia) is incorrect for a
supplementary actuator — it makes the motor take ~7 s to spin up, far
beyond the 0.8 s STS window.  Tune this value if the motor is still
too slow (decrease) or unrealistically fast (increase)."""

_FULL_POWER_T_DES: float = 1e6
"""Sentinel desired tension for 'full_power' mode [N].
Guaranteed to exceed tau_avail/J at any operating point, so the actuator
always clamps tau_cmd = tau_avail (full motor effort)."""


# ---------------------------------------------------------------------------
# Motor configuration
# ---------------------------------------------------------------------------

@dataclass
class MotorConfig:
    """Static configuration for one TSA motor unit."""

    lateral_offset_deg: float = 0.0
    """Frontal-plane offset angle α [degrees].
    Positive = dextral (towards right for right leg, left for left leg).
    Negative = sinistral.
    Effective sagittal moment arm: d_nominal × cos(α).
    For |α| < 15° the torque correction is < 3.5%."""

    activation_time: float = 0.0
    """Sim time [s] at which this motor activates.  Set to np.inf to disable."""

    name: str = ""
    """Human-readable label used in log_str()."""


def build_default_motor_configs(
    t_stagger: float = 0.5,
    alpha_deg: float = 8.0,
) -> List[MotorConfig]:
    """
    Four-motor layout: two central, one dextral, one sinistral.

    Activation is staggered in time so each new motor adds torque as the
    previous one's contraction builds.

    Parameters
    ----------
    t_stagger : float
        Time gap [s] between successive motor activations.
        Set to 0 to activate all four simultaneously.
    alpha_deg : float
        Frontal-plane offset of the outer two motors [degrees].
        Typical hardware value: 5–15°.
    """
    return [
        MotorConfig(lateral_offset_deg=0.0,        activation_time=0 * t_stagger, name="M0_center"),
        MotorConfig(lateral_offset_deg=0.0,        activation_time=1 * t_stagger, name="M1_center"),
        MotorConfig(lateral_offset_deg=+alpha_deg, activation_time=2 * t_stagger, name="M2_dextral"),
        MotorConfig(lateral_offset_deg=-alpha_deg, activation_time=3 * t_stagger, name="M3_sinistral"),
    ]


# ---------------------------------------------------------------------------
# Internal helpers
# ---------------------------------------------------------------------------

def _build_tsa_sim(sim_id: int, L: float) -> TSASimulator:
    """TSASimulator with exo knee parameters (gravity_along_string=False)."""
    return TSASimulator(
        id=sim_id,
        L=L,
        radius=0.004,
        payload_mass=_PAYLOAD_MASS_INIT,
        I_motor=5e-5,
        pretension_theta=10 * np.pi,   # 5 turns
        max_motor_torque=0.1668,   # MP motor: 1.7 kg·cm → 0.1668 N·m
        no_load_speed=800 * 2 * np.pi / 60,   # 800 RPM → 83.8 rad/s
        b_theta=1e-4,
        b_X=0.0,
        gravity_along_string=False,
        max_contraction_ratio=0.30,
    )


# ---------------------------------------------------------------------------
# MotorUnit
# ---------------------------------------------------------------------------
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
